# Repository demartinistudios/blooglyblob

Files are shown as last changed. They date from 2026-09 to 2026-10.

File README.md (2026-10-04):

<a href="https://demartinistudios.github.io/blooglyblob/">
  BlooglyBlob — open the build guide
</a>

# BlooglyBlob

**A 3D-printable AI companion that runs on Raspberry Pi and uses the OpenAI
API.**

Press the button to start a voice conversation. BlooglyBlob talks back, lights up,
moves his head and arms, and can dance to music. You build the character from
printed parts and purchased electronics, then install the Python application on
the Pi.

This repository contains the application, editable CAD, STL files, Bambu Studio
print projects, and illustrated assembly instructions.

**[Open the build guide →](https://demartinistudios.github.io/blooglyblob/)**

<a href="https://demartinistudios.github.io/blooglyblob/">
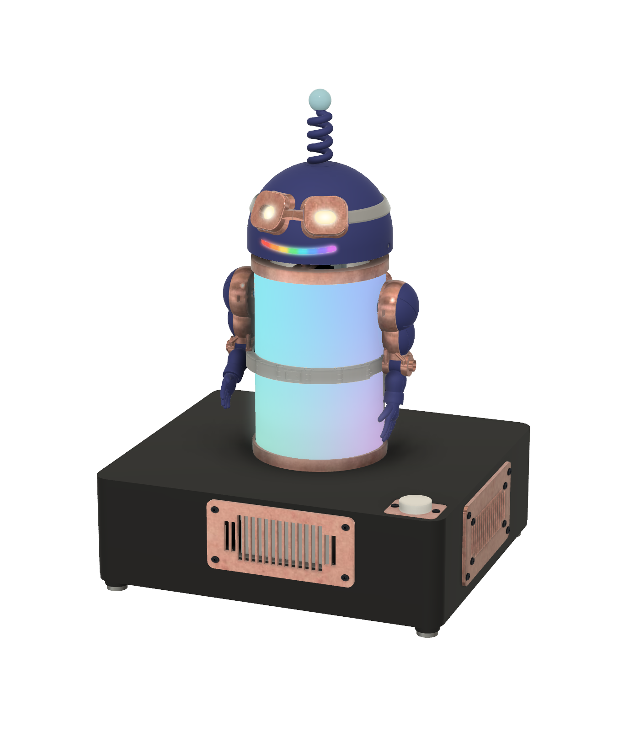
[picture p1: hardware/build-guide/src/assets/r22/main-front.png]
CAD view of BlooglyBlob lit up: glowing goggle eyes, a rainbow mouth and a softly lit body, with blue-violet head and hands, copper trim, and a black base with a conversation button
  
</a>

## Build your own

Start with the [build guide](https://demartinistudios.github.io/blooglyblob/).
It brings the parts list, print downloads, assembly drawings, wiring, Pi setup
and software commands together in one numbered sequence. You can read it and
download the print files without cloning this repository.

- **[Parts and supplies](https://demartinistudios.github.io/blooglyblob/#parts):** what to buy, quantities and tools.
- **[Print the parts](https://demartinistudios.github.io/blooglyblob/#step-print-plates):** Bambu Studio projects, raw STLs, plate layouts and print settings.
- **[Set up the Raspberry Pi](docs/software/setup.md):** Raspberry Pi Imager, Wi-Fi, credentials and installation commands. This is also covered in the guide.

The build uses a Raspberry Pi 3 Model A+, USB audio, speakers, NeoPixel LEDs and
servos. Expect 3D printing, soldering and some terminal commands. You'll need a
computer for setup, an internet connection and your own OpenAI API key with API
billing enabled. Conversations use cloud AI; API usage is billed separately from
a ChatGPT subscription. See the guide's parts list for the complete specifications.

**Project status:** this is a working development project, with physical assembly
and full-system validation still in progress. Review the
[current limitations](docs/release/publication-inventory.md#readiness-and-validation-scope)
before buying or printing parts.

## Using or changing the software

One Python application runs on the Pi and controls conversations, audio, lights
and movement. The installer sets it up as a service so it starts when the Pi boots;
the button starts a conversation.

- [Setup](docs/software/setup.md) — install and configure the application.
- [Maintenance](docs/software/maintenance.md) — update, inspect logs and troubleshoot.
- [Architecture](docs/software/architecture.md) — how the application and OpenAI connections work.
- [Contributing](CONTRIBUTING.md) — development setup, tests and contribution workflow.

Run `make help` from a checkout to see the available commands. Follow the setup
guide before running commands against a Pi.

## Find your way around the repository

| Location | What's there |
| --- | --- |
| [`blooglyblob/`](blooglyblob/) | Python application and device control |
| [`hardware/cad/`](hardware/cad/CURRENT-DESIGN.md) | Current editable CAD and exported geometry |
| [`hardware/printing/`](hardware/printing/current/README.md) | Bambu Studio projects and print guidance |
| [`hardware/build-guide/`](hardware/build-guide/README.md) | Guide source and local preview instructions |
| [`docs/software/`](docs/software/) | Setup, maintenance and software architecture |
| [`tests/`](tests/) | Automated software tests |

Open the full assembly as [Fusion (.f3d)](hardware/cad/current/assembly.f3d) or
[STEP AP214 (.step)](hardware/cad/current/assembly.step) in other CAD applications.
The STEP includes hidden reference and test geometry; see the
[CAD notes](hardware/cad/CURRENT-NOTES.md#portable-assembly).

For hardware or guide contributions, read the [hardware workflow](hardware/README.md).

## Safety and license

Build and use at your own risk. No safety or performance guarantees are made.
You are responsible for assembly, testing and use. BlooglyBlob is a hobby
project for adults, not a toy, and is not designed for children. The hands use
small, strong magnets that are dangerous if swallowed, and the microphone sends
speech to OpenAI under your API account. Read the
[safety and responsibility notice](hardware/SAFETY.md) before starting.
BlooglyBlob is not affiliated with or endorsed by OpenAI or any other company
named here. Raspberry Pi is a trademark of Raspberry Pi Ltd.

Original software, hardware designs and build materials are [MIT licensed](LICENSE).
See [license scope](LICENSING.md) for exclusions and separate audio terms.

The optional streaming feature uses TMDB and the TMDB APIs but is not endorsed,
certified, or otherwise approved by TMDB. Streaming availability data comes from
JustWatch through TMDB; optional deep links use data from
[Watchmode](https://www.watchmode.com/).

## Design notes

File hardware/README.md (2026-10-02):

# Hardware

For assembly, open the [build guide preview](build-guide/README.md#build-and-preview).
The guide’s **Build cost** page lists materials used, shopping totals and a
shopping list with purchase links; [BUILD-COST.md](catalog/BUILD-COST.md)
explains how they are calculated.
Website deployment and physical qualification are separate checks. For contributions, this page
connects the three area procedures:
[CAD](cad/DESIGN-WORKFLOW.md), [printing](printing/current/README.md), and
[guide authoring](build-guide/README.md). A contributor or fork can inspect the
current inputs, build the guide and propose changes without maintainer credentials
or Fusion MAIN access. An authorized maintainer performs upstream CAD promotion.

## Start from a fresh checkout

Use Python 3.12 or 3.13 and run these commands from the repository root. These
offline commands use only the Python standard library; the full
[development setup](../CONTRIBUTING.md) is needed for application work:

```sh
make hardware-check
make guide-build
```

If `python3` selects another version, add `HOST_PYTHON=python3.12` to each Make
command.

The first command checks offline invariants. Outstanding publication reviews are
separate: use `python3 hardware/tools/validation/check.py --publication` to inspect
them. The second
builds a local preview; success does not authorize publication. Neither requires
Fusion, Bambu Studio, scratch outputs, credentials or
physical devices. Browser verification and optional authoring dependencies are
in the [guide procedure](build-guide/README.md).

## Sources of truth

| Information | Maintained source |
| --- | --- |
| Accepted CAD identity and exact cloud version | [Registry](cad/design-control/registry.json); [current design](cad/CURRENT-DESIGN.md) is its generated summary |
| Required native and geometry exports | [Current CAD inputs](cad/current/), selected and hash-checked by the registry's input lock |
| Part identity and dependencies | [Part catalog](catalog/parts.json) |
| Editable print projects and process | [Current print set](printing/current/README.md) and [recipe locks](printing/recipes/projects.json) |
| Installed hardware and electrical allocations | [Hardware allocations](assembly/hardware.json) and [electrical tables](assembly/electrical.json) |
| Current technical limitations | [CAD notes](cad/CURRENT-NOTES.md), [print procedure](printing/current/README.md), and [guide review](build-guide/REVIEW.md) |
| Price quotes and consumption allowances | [Price catalog](catalog/prices.json); the guide calculates costs from these quotes, current quantities and plate weights |
| Purchased supply specifications | [Supply catalog](catalog/supplies.json); guide cards add presentation and links |
| Component references | [Reference catalog](references/community-20260925/catalog.json) linking to publisher documents |
| Assembly instructions | [Guide source](build-guide/src/), independent of CAD release selection |

Everything for the physical character belongs under `hardware/`, including
references, illustrations, tools and records. Software and repository-wide docs
belong under `docs/`; Pi device-control modules remain in `blooglyblob/hardware/`.

## One process, with separate stages

One person can perform all stages, or several owners can hand them off using the
same records and checks. Agree ownership before editing shared files.

1. Record the intent, accepted baseline, expected affected parts/interfaces and
   acceptance criteria in a unique ignored experiment run. Work in a separate
   CAD document; render or print trials only within the authorized scope.
2. Review the candidate's evidence and limitations. An authorized owner promotes
   only the accepted scope using the [CAD procedure](cad/DESIGN-WORKFLOW.md).
3. Identify affected geometry, placements, hardware, material/process, electrical
   and software dependencies. Record each downstream stage as `pending`,
   `blocked` or `verified` against its exact inputs. An unmapped impact needs
   review; a new global revision alone does not require rebuilding every output.
4. Update or verify affected [print recipes](printing/current/README.md) and
   [guide surfaces](build-guide/README.md). Record changed, reused and reviewed
   outputs with concise public evidence in the current review/provenance files;
   keep the detailed work record private.
5. Run offline checks, guide build and browser verification; review the assembly
   meaning and visuals before claiming a synchronized public build kit.

CAD may be accepted while printing or guide work remains pending. A qualified
build-kit release requires those dependencies and blockers to be resolved.
The development source and guide can be shared with their limitations stated;
see the [release checks](../docs/release/checklist.md).
Digital validation, machine completion, usable stock and physical fit/strength/
optical qualification are distinct evidence. A passing slice does not establish
physical qualification; printing and deployment are separate authorized actions.

## Retention

Keep one current required set of native CAD, geometry exports and editable print
inputs in Git, with compact provenance, exact hashes and current limitations.
A CAD checkpoint may precede print or guide acceptance. Guide prose changes need
no CAD release.

Keep experiments, candidate slices, renders and transaction backups in ignored
`hardware/.work/<category>/<run-id>/`. Existing detailed work records remain local
under ignored `hardware/records/`; printer queues, stock and job history belong in
ignored `hardware/printing/operations/`. Record owner, baseline, purpose, useful
results and next action there. Publish maintained inputs and necessary technical
conclusions, not work diaries or entire run trees.

Before cleanup, confirm ownership, identify all consumers and privately back up
unique useful work. Git does not protect ignored or uncommitted files. Keep active
work until its owner releases it; never make a public build depend on local notes.

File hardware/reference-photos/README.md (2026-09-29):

# Servo and horn reference photographs

Original project photographs document the Kitronik 25105 servo kit and its disk
horn. They show component identity, face features and hole arrangement. Perspective
prevents using the ruler or caliper display in an image as a precise dimension.

| Photograph | Shows | SHA-256 |
| --- | --- | --- |
| [Servo and supplied horns](kitronik-25105-servo-and-horns.jpg) | Kitronik 25105 label; disk, single-arm, double-arm and cross horns; screws | `7322c0b13f656a358c2336e57be936af8b65a79d01c99e360f1ec55198ba8b92` |
| [Disk spline face](kitronik-25105-disk-spline-face.jpg) | Raised center with splined socket on the servo-facing side | `059b7cd5e392d88aa05b36925ba0a877f83cc8d71fe194da4269afceabe6fa25` |
| [Disk outer face](kitronik-25105-disk-outer-face.jpg) | Smaller raised center around the screw opening | `a2165811ba410bba2b3c9a426b5e0594c0c1eafebf44c10f703b969b42033f11` |

The [servo reference](../servos/README.md#measured-disk-horn) records the separately
measured dimensions, including plate thickness, raised centers, mounting-hole
spacing and seated height. Consult its manufacturer links for the servo case and
spline specification. Measurements of this reference sample are not manufacturing
tolerances or proof of fit for every supplied horn.

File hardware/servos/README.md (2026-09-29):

# Servo reference: Kitronik 25105 / FS90MG-CL

The head and both arms use Kitronik Clippable Servo 25105, identified by Kitronik
as the Feetech FS90MG-CL. Each axis uses the supplied round disk horn and its
matching center screw. Follow the [build guide](https://demartinistudios.github.io/blooglyblob/)
for drilling, fastening and fitting the horns.

## Manufacturer references

- [Product page](https://kitronik.co.uk/products/25105-clippable-servo)
- [Technical drawing](https://resources.kitronik.co.uk/pdf/25105-kitronik-clippable-servo-technical-drawing.pdf): case, mounting ears, output and mounting-hole dimensions.
- [FS90MG-CL datasheet](https://resources.kitronik.co.uk/pdf/25105-kitronik-clippable-servo-fs90mg-datasheet.pdf): 21T spline and nominal 180° travel over 500–2500 µs.

Use the product-specific documents when selecting a replacement. Generic FS90MG
listings describe different analog/digital variants, spline counts and envelopes;
the name alone does not establish compatibility. The supplied horn center screw
is a separate interface from the M2 servo mounting screws.

## Nominal case dimensions

These dimensions are taken from the Kitronik drawing and used by the CAD
reference. They do not include print clearance or establish physical fit.

| Dimension | mm |
| --- | --- |
| Main body length × width | 22.5 × 12.1 |
| Main rectangular case height envelope | 22.4 |
| Height excluding spline / including spline | 26.7 / 30.7 |
| Mounting-ear overall span | 32.3 |
| Ear underside / top from case bottom | 15.7 / 18.2 |
| Mounting-hole spacing / diameter | 27.7 / 2.2 |
| Output axis to nearer mounting hole | 8.7 |
| Spline envelope diameter | 4.86 |

The CAD reference simplifies the molded case and output cap. Axis-to-case-end
placement uses symmetry inferred from the drawing.

## Measured disk horn

The [reference photographs](../reference-photos/README.md) show the supplied kit
and both disk faces. The following are measurements of the reference horn, not
manufacturer tolerances or measurements inferred from photograph scale.

| Feature | Diameter | Axial thickness / protrusion |
| --- | --- | --- |
| Flat disk plate | 23.55 mm | 1.61 mm |
| Servo-facing raised center | 6.75 mm outside | 2.17 mm above the plate face, derived as 3.78 − 1.61 |
| Outer raised center | 5.44 mm outside | 0.87 mm above the plate face, derived as 4.65 − 3.78 |
| Plate plus servo-facing raised center | — | 3.78 mm |
| Overall, including both raised centers | — | 4.65 mm |

The measured installed height is 3.33 mm from the uppermost flat plastic
output-cap face to the disk's broad underside, or 4.94 mm to its upper flat face.
The selected opposite mounting holes are approximately 18 mm apart and originally
about 1.1 mm in diameter; the guide specifies drilling that pair to 2.2 mm with
the horn removed. Other pairs are about 16 and 20 mm apart, so the holes do not
form a uniform four-hole pattern. Use the guide's current fastener allocations.

The horn envelope omits the spline socket, center bore and mounting holes.
The 6.75 mm measurement is the outside of the raised center, not the socket
diameter. Do not infer spline engagement or installed height from that envelope.
Keep access to the supplied center screw; the printed adapter fastens to the horn
rather than replacing its spline.

## Fitting and operating positions

The application uses a fixed **1000–2000 µs window at 50 Hz**. The fitting command
`make pi-servo-fit` holds the left arm at 2000 µs, right arm at 1000 µs and head at
1500 µs before the guide's horn installation steps. See
[servo setup and maintenance](../../docs/software/maintenance.md) and the
[servo fitting contract](../../docs/software/validation.md#servo-fitting-contract).

The datasheet gives no case-referenced angular zero or marked-tooth datum.
Horn indexing establishes the attached part's orientation. Nominal datasheet
travel does not establish loaded clearance, cable freedom or usable travel in the
assembled robot; physical qualification remains separate from the reference data.

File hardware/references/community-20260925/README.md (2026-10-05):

# Component reference catalog — 2026-09-25

[Catalog](catalog.json) maps required parts, consumables and fasteners to publisher product pages, pinouts, drawings and datasheets. Documents are external links. `download_url`, when present, selects the document endpoint for the guide; otherwise it uses `official_url`. Publisher PDFs are not version controlled or bundled. Optional research downloads belong in ignored `hardware/.work/` and are never required by a build.

The catalog is a reference supplement. It does not approve substitutions, qualify physical fit, change electrical limits or advance CAD/delivery acceptance.

## Coverage and limits

- Manufacturer-hosted PDFs cover the Kitronik servo, Adafruit eye boards and Pixel Shifter, Panasonic capacitor, Raspberry Pi board, MEAN WELL supply, Adafruit power-donor cable, YAGEO resistors and Zotefoams LD45. The two Kitronik links identify the manufacturer PDFs inspected on 2026-09-17.
- The Eaton S505H PDF is Eaton Technical Data 4406, effective June 2023, manufacturer-authored and hosted by LCSC. The build uses its 1 A time-delay selection for F2 in the single E07 holder. The catalog selects the verified distributor-hosted PDF because Eaton’s download endpoint is unreliable.
- The WAGO connector PDF is manufacturer-authored and hosted by NetXL; the catalog also links directly to WAGO's exact product page. This supplier mirror is explicitly identified.
- Exact product pages provide references for the Adafruit connector cables, mouth stick, speaker pair, button and quick-connect leads, plus Waveshare USB TO AUDIO and its supplied extension. The PNY Elite family page covers the selected 32 GB microSDHC card. The button has a publisher raster drawing link; it is not mislabeled as a PDF. The servo horn and center screw lack a separate manufacturer dimensional specification.
- Switchcraft 721AU and K&J D31 have verified official PDF links. Family documents are labeled and must be read for the specified variant.
- **E05 is Adafruit6026.** The exact product and manufacturer drawing establish the100-pixel,100mm-pitch strand. Adafruit family guides describe copper-marked positive conductors and factory lead colors. Lot variation remains possible; confirm identification and test input direction before cutting. Connector sex is not direction.
- **E24 and E25 use specification-matched purchasing examples.** E24 links to a 24 AWG DigiKey jumper lead and its datasheet. E25 requires four equal-height adhesive feet fitting the Ø14mm post faces. There is no defensible exact-model datasheet to attach.
- **C08 is a candidate, not a verified installed purchase.** K&J D31 matches the stated size. Retention and adhesive compatibility remain to be tested.
- **C02/C03/C04:** the user's selected [Coscom LD45 listing](https://coscomcosplaysupplies.com/products/plastazote-ld45) explicitly offers white 4 mm sheets. Its default selector is 2 mm, so purchasers must select 4 mm. The [Zotefoams LD45 sheet](https://www.zotefoams.com/wp-content/uploads/2025/03/PIS-A013-Plastazote-LD45.pdf) is Product Information Sheet A013, Issue 1 Revision 1, June 2026. It gives typical material properties, not guaranteed optical transmission. The superseded December 2017 URL returned 404; the current URL was obtained from Zotefoams' product information index.

## Verification and updates

The owner selected external links on 2026-09-26. The [link verification record](link-verification.json) records the September link scan and the three generic servo datasheets; later additions carry their own checked dates in the catalog. Direct PDF retrieval checks the PDF signature rather than treating an HTML error page as a document. Browser retrieval verified Panasonic and product pages that blocked or timed out under command-line access. These are dated availability observations; external sites can change.

Edit `catalog.json` as the authority, then update the guide's reference presentation and page. Preserve part identity, exact-model/family limitations and publisher or supplier-host attribution. Verify replacement links against the intended document before changing them. Do not recreate download-and-copy generators or add manufacturer PDFs to the source tree.

`make hardware-check` checks external URL shape, catalog/guide agreement, rendered-page links and the absence of publisher PDFs in the reference/servo directories. `make guide-browser` verifies the built guide. These contributor checks remain offline; deliberate live link verification is separate.

`tool-product-identity.json` records the separate tool check: Adafruit 136 is Ladyada’s Electronics Toolkit, whose contents link to Adafruit 2034, Digital Multimeter Model 9205B+. The current guide T03 photo uses 2034 but its purchase link pointed to 136 when checked; the guide owner was notified.

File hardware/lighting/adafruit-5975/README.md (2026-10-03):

# Selected eye board: Adafruit 5975

The build uses **two** Adafruit 5975 boards, one per eye, behind removable
Plastazote diffusers. The boards fasten to printed holders so they can be replaced
without glue.

- [Product and published envelope](https://www.adafruit.com/product/5975): 12.3 × 11.3 × 6.2 mm, M2 mounting, 3-pin JST-SH input/output.
- [Adafruit PCB source](https://github.com/adafruit/Adafruit-NeoPixel-Breakout-PCB), linked by the [manufacturer downloads page](https://learn.adafruit.com/adafruit-neopixel-breakout/downloads).
- Local unmodified source: [Eagle board](Adafruit-NeoPixel-JST-SH-Breakout.brd), [upstream README](upstream-README.md), [upstream license](upstream-license.txt). Designed by Limor Fried/Ladyada for Adafruit Industries; upstream identifies Creative Commons Attribution/Share-Alike. Preserve the supplied attribution and license with redistribution of these reference files.
- Local unmodified 3D model: [5975-NeoPixel-Breakout.step](5975-NeoPixel-Breakout.step), byte-identical to `5975 NeoPixel Breakout.step` in [Adafruit CAD Parts](https://github.com/adafruit/Adafruit_CAD_Parts). Copyright (c) 2016 Adafruit Industries, [MIT license](../../../LICENSES/Adafruit-CAD-Parts-MIT.txt).
- [Extracted mechanical interface](mechanical-interface.json), including source SHA-256, exact hole coordinates, outline dimensions and limits of the extraction.

The Eagle file uses millimeters. Two plain holes have diameter 2 mm and centers (0, +4.318) and (0, −4.318): **8.636 mm apart**. The LED is centered at (0, 0). Layer 20 outlines a 12.192 × 11.43 mm rounded board, with 2.54 mm corner radii. These are CAD nominal dimensions, not physical measurements or print clearances. The small difference from the product listing is retained explicitly rather than rounding the mounting pattern.

The overall 6.2 mm product envelope does not define the full front/back component
stack. Keep both connector plugs and wiring bends accessible; use the maintained
assembly instructions for screws, nuts and washers.

## Assembly use

The eye boards mount in P06 holders. Follow the
[build guide](https://demartinistudios.github.io/blooglyblob/) for diffuser placement,
fastening and wire routing. The selected [current design](../../cad/CURRENT-DESIGN.md),
[assembly allocations](../../assembly/hardware.json) and
[electrical tables](../../assembly/electrical.json) define the maintained build.
This reference does not replace those quantities, fastening choices or wiring.

Flexible wiring, physical plug access, diffuser fit and optical performance still
need physical review. The nominal foam thickness is 4 mm; it is not a measured
fit or guaranteed optical specification. Preserve access for both plugs and
avoid deriving the full component stack from the product envelope alone.

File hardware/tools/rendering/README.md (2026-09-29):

# Current rendering

Install `requirements.txt` into a local virtual environment. Dependencies were exercised with Python 3.12; the lock records exact installed versions. Do not commit the environment.

```sh
python hardware/tools/rendering/run.py --view r22/part-GS11 --font /path/to/licensed/font.ttf --output hardware/.work/rendering/new-run
```

Use `--view eye-details` for the five eye-interface illustrations. Other scene keys are in `hardware/rendering/scenes/views.json`. The runner resolves all inputs through `hardware/rendering/source-lock.json`,
checks the selected CAD identity and native/export bindings, and requires a new
output directory. Roles select current meshes, native mesh evidence, assembly,
joints, palette and scenes without relying on historical payload folders.
Scene dimensions must be explicitly reviewed for the selected CAD identity. It renders the current composed meshes directly. Cameras, palette, occurrence transforms and cm→mm conversion are retained. Each run records package versions and the supplied font's hash; the original illustration font was macOS Arial. Supply a legally available matching font for exact typography, or review the visual differences. No font is redistributed here.

A new native geometry export must update the current composed mesh and its provenance deliberately. Inspect bounds, volume, joints, appearance and visibility; keep unchanged rows exact. Review generated images before promoting them into guide source. Original CAD inspection screenshots remain immutable evidence and are not synthetically recreated by this renderer.

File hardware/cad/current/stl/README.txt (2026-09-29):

R23 geometry set: FB01 and FB41 replaced as a matched pair. FB41 is 2mm thick; four M3x6 screws/M3 nuts; round base mounts replace square posts. All other STL bytes unchanged from R22. 52 required shapes/75 installed pieces plus optional AR07; AR10/AR11 omitted. Bed transforms are explicit; FB41 front down. Geometry only: existing R22 C2/K1 project meshes and toolpaths are obsolete for FB41/FB01 and must be replaced and re-sliced. Printed fit, 1mm bearing web and 0.3mm nominal audio clearance are unqualified.

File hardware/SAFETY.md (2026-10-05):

# Safety and responsibility

## Your build, your responsibility

BlooglyBlob is a DIY electronics and robotics project. You are responsible for selecting components, printing, assembly, wiring, software configuration, inspection, testing, maintenance and use of your build, including any modifications. Evaluate whether you have the skills and equipment to do the work; get qualified help when needed. Following this guide or passing its checks does not establish that a build is safe, compliant or suitable for a particular person or purpose.

## Who it’s for and practical precautions

BlooglyBlob is a hobby electronics project for adults, not a toy, and is not designed for children. Keep it, and especially its small magnets, away from young children.

- Soldering, cutting and printing involve hot surfaces, fumes and sharp tools. Follow equipment and material instructions; use suitable ventilation and protective equipment.
- Use the specified Mean Well GST40A05-P1J (5 V, 5 A) power supply. The circuit is designed around its output and protection characteristics; do not substitute another supply.
- Fit the specified T1 A time-delay fuse in the lighting supply. Do not bypass it or fit a higher-rated fuse. Supply protection and the fuse do not guarantee that every fault clears before wiring or components overheat.
- Do not open the supply or work on mains wiring. Disconnect power before changing wiring; short circuits can cause burns or fire even at low voltage.
- Keep fingers, hair and clothing away from servos and joints. A jammed servo can keep pushing and overheat; stop immediately. Keep small parts away from young children and pets.
- The hands attach with small, strong magnets. If swallowed, magnets can cause serious internal injury. Check that each magnet is fully set in cured epoxy and inspect the hands regularly. Keep loose magnets and detachable hands away from young children and pets. If a magnet may have been swallowed, get medical help immediately.
- Keep the build dry, keep vents clear, and stop using it if wiring is damaged, parts overheat, or movement is obstructed. Do not leave powered tests unattended.
- AI responses can be incorrect or inappropriate. Do not rely on the robot for emergency, medical or other safety-critical decisions.

## Privacy, cloud AI and costs

The robot’s microphone sends speech to OpenAI under your API account. Tell people who talk to the robot that its voice is AI-generated and that their conversations go to a cloud service. You are responsible for following OpenAI’s terms and usage policies, including its rules on use by children, and the laws where you live.

API usage is billed to your OpenAI account. Use its billing controls to limit what you can spend. You are responsible for all charges.

## No warranty or safety certification

To the fullest extent allowed by applicable law, the project’s designs, print files, software, documentation and build instructions are supplied as is, without express or implied warranties, including merchantability, fitness for a particular purpose and noninfringement. The authors and contributors make no guarantee of accuracy, completeness, reliability, performance or safety, and do not represent that a build meets product-safety standards or regulatory requirements. Diagrams, test results, recommended components and completed checklists are not safety certification.

## Limits of liability

To the fullest extent allowed by applicable law, the authors, contributors and copyright holders disclaim liability for injury, property damage, data loss or other loss arising from building, modifying or using this project. Build and use it at your own risk. Nothing in this notice excludes a liability, warranty or legal right that applicable law does not allow to be excluded. The project license and third-party terms continue to apply; this notice does not replace them or add restrictions to the open-source license.

BlooglyBlob is not affiliated with or endorsed by OpenAI, Adafruit, Raspberry Pi Ltd, Autodesk or any other manufacturer or service named in this project. Product names and trademarks belong to their owners.

See the [MIT license](../LICENSE) and [license scope](../LICENSING.md).

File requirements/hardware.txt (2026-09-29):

# Additional Raspberry Pi audio and GPIO dependencies.
pyaudio>=0.2.14
gpiozero>=2.0
pigpio
rpi-ws281x>=5.0.0
RPi.GPIO>=0.7.1

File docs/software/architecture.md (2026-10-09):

# Application architecture

Blooglyblob runs as one Python application on the Raspberry Pi, started with
`python -m blooglyblob` and managed by `blooglyblob.service`. The button starts
a conversation. OpenAI supplies cloud AI; there is no local language model.
Follow [setup](setup.md) and [maintenance](maintenance.md)
for installation and operation.

## Internal responsibilities

| Module | Owns |
| --- | --- |
| `blooglyblob/application.py` | Startup, readiness, signals, shared API client, integrations, and shutdown |
| `blooglyblob/conversation.py` | Conversation, idle, dance, and alert transitions; activity generations and tool context |
| `blooglyblob/media.py` | Direct speech, scanner, drain, and media-release coordination |
| `blooglyblob/audio/` | Microphone capture, bounded PCM handoff, one speaker owner, mixing and resampling |
| `blooglyblob/hardware/` | Button, LEDs, servos, presentation, local dance/chime workers and diagnostics |
| `blooglyblob/ai/` | OpenAI Live, Responses, Speech, validation, persona and voice resources |
| `blooglyblob/tools/` | Tool schemas/execution, timers, Ring, Roku, and content lookup |

These modules call one another directly. There is no local brain/device server,
network protocol, device registration, or reconnect loop. OpenAI connections
still use the internet. The existing `pigpiod` daemon remains a GPIO prerequisite.
The application retains the root permissions required by the current LED/GPIO drivers.

## Settings and voice

Select one runtime file with `BLOOGLYBLOB_ENV_FILE`; the installed service uses
`/etc/blooglyblob/app.env`. Explicit process values take precedence. Files are
read literally without shell execution or variable interpolation. The root
`.env` contains host-side deployment settings and is not loaded by the application.

Bring your own `OPENAI_API_KEY`. Live, Responses, and Speech requests are billed
to your account. Defaults remain `gpt-live-1`, `gpt-5.6-terra`, and
`gpt-4o-mini-tts`, respectively; your account must support the configured models.
The [runtime template](../../config/app.env.example) lists model, audio and
integration settings. `OPENAI_INACTIVITY_SECONDS` defaults to 20 and
`OPENAI_SESSION_MAX_SECONDS` to 600. These bound one conversation, not total
spending. No provider fallback exists.

`blooglyblob/ai/persona.json` defines the character.
`blooglyblob/ai/voice_profile.json` supplies Ballad, delivery instructions, pace,
expression and pronunciation. `OPENAI_VOICE` overrides the shared voice;
`OPENAI_SPEECH_VOICE` can override finite announcements separately. The APIs use
different synthesis paths, so matching settings still need a listen on the Pi.

Optional ring modulation uses the profile's `output_effect` settings. It is
currently disabled (`mix: 0.0`), which preserves PCM unchanged. `mix` ranges
from 0.0 to 1.0; integer `carrier_hz` ranges from 1 to 400. It preserves sample
count, adds no lookahead or buffered tail, and never increases individual sample
magnitude. There is no automatic loudness processing or replacement DSP.
Restart the application after a profile change. Deploy accepted profile edits
with `make pi-update`; installed source edits are replaced by the next update.
Audio tuning and the existing clipping/follow-up investigation remain separate
from this architecture change.

## Audio formats

Internal speech is mono, signed 16-bit PCM at 24 kHz. The microphone captures
48 kHz and one continuous SoXR converter produces 24 kHz directly. Live receives
those samples unchanged, framed and paced for transport. Incoming Live/Speech
PCM stays at 24 kHz through optional coloration; the speaker writer converts it
once to the device's 48 kHz rate.

The same converter prepares the 16 kHz scanner recording once at startup and
converts the 16 kHz alert during file playback. Dance plays at its native
44.1 kHz stereo rate. Converted streams preserve filter state between packets;
normal completion flushes the short filter tail, while cancellation discards it.
There is no intermediate 16 kHz microphone format or codec transcoding. Current
device selection and microphone gain remain unchanged.

## Conversations and activities

Greeting preparation runs after local readiness and can make a billable Speech
request even before the first button press. A prepared greeting is reused;
otherwise Speech streams it on demand. Its existing voice and speed are retained.
Live connects concurrently. Microphone input is withheld until the greeting
physically drains, to avoid forwarding that locally generated speech as input.
Normal duplex capture resumes immediately afterward. A bounded queue covers any
remaining Live connection setup; stopping discards that session's input.

The scanner loops quietly through the conversation's speaker writer during web
search. Speech lowers its volume; microphone capture and incoming speech keep
flowing. Completion, failure or cancellation removes the effect. Background-only
samples do not drive talking gestures. Dance and
alert recordings use sequential speaker ownership.

When Live delegates a request, the application withholds speculative playback
while Responses decides which tool or answer is needed. This decision does not
close the microphone. Selecting a nonterminal tool reopens speech before the
work runs, so conversation can continue over the ducked scanner sound. Sleep and
dance keep playback withheld until the application's single finite announcement.
A result, failure, or new user speech releases the decision gate; the backend's
request deadline bounds the wait. New speech cancels an undecided request. Work
already running can continue, but older context cannot subsequently authorize a
sleep or dance transition. Tool arguments still pass schema validation; uncertain
actions are not automatically replayed under a new call ID.

Sleep/dance announcements must physically drain before the action starts.
Matching dance completion returns to conversation with the existing greeting.
Timers and doorbell alerts retain their preemption, acknowledgement, dismissal,
and time-limit behavior. An alert during an active alert is dropped; overdue
saved timers are discarded at startup rather than replayed.

Meaningful conversation activity resets inactivity; silent PCM does not. Owned
tool work suspends inactivity shutdown while the overall session ceiling still
applies. Optional integrations retain their existing roles and configuration.

## Completion and failure rules

- The conversation owns activity and generation decisions. Presentation never
  determines whether microphone input is accepted.
- Audio owns every speaker stream. Queue acceptance, effect removal, physical
  drain, and full driver release are distinct completions.
- The button mutes locally before waiting for the event loop or cloud. Stale
  audio and action results cannot reactivate a retired generation.
- Native workers must finish before their resources are released or reused.
  Cancellation of an await does not mean its thread stopped.
- Routine provider failure with confirmed closure returns to idle. Missing
  final usage alone is a warning when transport closure is confirmed.
- Unconfirmed ownership mutes and stops the application with exit status 73.
  The service does not automatically restart that status; inspect logs and
  restart explicitly after resolving the cause. Startup and shutdown have
  finite deadlines, including foreground execution and Python thread teardown.

Talking gestures and body lights follow actual speaker level while conversation
remains listening. Silence, drain, flush, mute and failures clear that level.
Pose holds and animation locks remain authoritative; sleep, dance and alert
presentation retain their existing behavior. Eyes are controlled separately.
The supported 16-pixel data chain uses body indices 0–5, eyes 6–7, and mouth
8–15. The mouth is explicitly dark during normal operation; this profile update
does not add a mouth animation. The [LED diagnostic](maintenance.md#supported-led-chain)
exercises every pixel without changing the F2-protected lighting supply.

## Verification

`make pi-status` and `make pi-logs` describe the single application service.
Readiness means required local initialization and controls completed; it does
not open a conversation or prove cloud access, acoustic quality, or movement.

`make dev-check` runs formatting, lint, type checks, and hardware-free tests without API
credentials. The [validation coverage](validation.md) separates offline checks
from physical qualification, including capture clipping and follow-up behavior
that still need evaluation in the complete assembly.

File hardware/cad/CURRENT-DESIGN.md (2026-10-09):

# Current Blue Glee Blob design

Open **Blue Glee Blob - MAIN** in Fusion → Admin Project.

Accepted design **R33**, exact cloud version **v30**.
Permanent file ID: `urn:adsk.wipprod:dm.lineage:nkM4P_10T7yYk-tasXlhbg`.

## CAD acceptance record

Recorded when this CAD revision was accepted; delivery status above may supersede downstream status below.

Accept the chamfered front upright P43, reinforced flush head-servo carrier P04, distinct lower P11/upper P42/rear-mounted middle P12 light brackets, and six LED placements. Retire P13 wire guide; rear P02 and unrelated geometry remain unchanged. Full native and STEP reimports verified; guide update remains pending.

## Current inputs

[Fusion assembly (.f3d)](current/assembly.f3d) · [STEP assembly (.step)](current/assembly.step) for other CAD applications.

[Native assembly and selected exports](current/) · [Parts catalog](../catalog/parts.json) · [Print projects](../printing/current/) · [Build guide](../build-guide/README.md)

The registry selects CAD authority. Its mandatory input lock is checked even without a delivery. A delivery binds the print recipes, parts catalog and renders to that CAD; it does not approve physical fit. The build guide is not part of the release: it reads these files when it is built.

## Checks

`python3 hardware/cad/design_control.py check` validates the mandatory current set, accepted native and any selected delivery.

The [workflow](DESIGN-WORKFLOW.md) defines experiments, promotion and recovery.

No local check queries live Fusion or establishes print completion, fit, strength or optical acceptance.

Generated from [registry.json](design-control/registry.json); use the render command after a reviewed registry update.

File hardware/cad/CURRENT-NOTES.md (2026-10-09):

# Current hardware notes

The registry selects R33, Fusion cloud version 30. The native assembly, STL
exports and print projects are the maintained build inputs. Historical revision
names in current evidence identify the source of unchanged features.

## Portable assembly

Download the [Fusion assembly (.f3d)](current/assembly.f3d) or the
[STEP AP214 assembly (.step)](current/assembly.step). The STEP exports the full
R33/cloud30 assembly, including hidden reference, layout and test components.
Reimport into Fusion retained all 562 bodies and 330 occurrences in their assembly
positions. It contains geometry and component placements, without Fusion
parametric history or joints. Body names and occurrence suffixes may change on import.
[Export provenance](current/step-export-provenance.json) records the source,
hash and measured reimport checks.

## Body lighting and head carrier

R33 uses five changed pieces: P43 front upright, P04 head-servo carrier,
P11 lower light bracket, P42 upper light bracket and P12 rear-mounted middle
light bracket. P02 is now the unchanged rear upright only. The P13 wire guide
is retired. There are 70 required printed pieces across 52 types, plus one
optional print instance. P10 seam covers, base and shoulder carrier are unchanged.

P43 has a deeper front chamfer, local fastening lands and an inset P04 mounting
seat. Its opposite M3 nut recess is fully recessed relative to the post's flat
side; the chamfer exposes part of the perimeter. Use an M3×10 countersunk screw
for this sideways front carrier connection. Nominal projection is 0.34 mm beyond
the nut, so verify full nut engagement without crushing the printed seat. This
is the designed length, not a confirmed record of the owner's trial screw.
The rear carrier connection retains M3×20.

P04 thickens the front servo-ear crossbar to 5.3 mm with a shallow 1.8 mm nut
recess and 3.5 mm of solid bearing above it. Both servo screw heads face upward:
front M2×8 and rear M2×6, with ordinary M2 nuts below. The servo shaft points up
at the rear end of its body, away from the front post. Assemble the servo and
carrier on the bench while the underside nuts are accessible.

P11 and P42 mount behind the front upright using two M3×14 countersunk screws
and two M3 nuts. Install the upper light bracket before the servo carriers block
access. P12 retains the rear mounting and brings its LEDs forward to the middle
height. Retain six Pebbles and two ties per Pebble. The lower and middle pad ends
have a 6 mm gap: bend the lower top exits behind their pads and the middle bottom
exits toward the LED-facing side, after clearing the end ties. Keep excess slack
out of servo movement and screw access. The local modeled wire envelope is
5×0.95 mm with a 5 mm bend radius; the complete strand slack was not simulated.

[Native and interface evidence](current/evidence/body-lighting-r33.json) records
geometry and clearance checks. The accepted trial improved assembly and lighting;
it is not a quantified strength or optical qualification. The inherited carrier
tab edge has only 0.2 mm modeled upper-bracket clearance, while added reinforcement
clears its adjacent bracket root by 1 mm. Check printed parts before tightening.

Guide illustrations, assembly order, hardware lists and supply cards are pending
an independent guide update. CAD acceptance does not mark that work complete.

## Body foam reference

C04 is a display-only 4 mm shell, with radii 34.1–38.1 mm and height 114.3 mm.
Two round Ø14 mm holes lie on the shoulder X axis at Z = 90 mm. The rear (+Y)
seam has a continuous 2 mm gap, without windows, knife slits or edge notches.
Backing ribs remain unchanged; the foam edges compress against them.
[Native verification](current/evidence/body-foam-r32.json) and
[print reuse](../printing/current/checks/r32-print-reuse.json) record this reference-only update.
Guide images showing the foam require regeneration from the current render inputs.

## Electrical references

The assembly contains one lighting fuse holder, F2, in its accepted location.
The F2 placement and all eight arm joints remain unchanged by R33. See [native verification](current/evidence/fuse-reference-r31.json)
and [print reuse evidence](../printing/current/checks/r31-print-reuse.json).

## Enclosure and board layout

FB01 uses open nut recesses and flat adhesive mounting faces for four WAGO
connectors. The Raspberry Pi and paired level shifters use the R28 mounting
positions. The WAGO row is ordered W1, W3, W2, W4 from rear to front. Use the
current assembly drawing and electrical tables for connector orientation and
terminal assignments. Do not infer wiring from the connector order alone.

The front microphone grille uses four M3 × 6 screws and ordinary M3 nuts; the
rear grille uses M3 × 12. Front nuts are loaded before the audio cradle.
Rear vent, power jack and audio mounting recesses have open loading access.
Glue only the eight board nuts, four bottom-cover nuts and three audio-cradle
nuts. Hold the grille, rear-vent and power-jack nuts until their screws catch;
do not glue them. Fastener counts and allocations are maintained in
[hardware.json](../assembly/hardware.json).

## Head shelf

P08/P14 use the same three M3 × 8 screws and M3 nuts with the fastening
pattern rotated 60 degrees. Assemble this joint on the bench before installing
the head/mouth. The head shell and P31 remain unchanged.

P08/P14 use direct native STL exports with closed edges at exact serialized
coordinates. Their source frames and the Fusion design are unchanged;
[export provenance](current/stl/head-export-provenance.json) records the checks.

## Audio cradle

FB24 has a solid rear tape surface. Attach the USB module's rear face, opposite
the microphones, to that surface with tape under 1 mm thick. Do not cut open the
closed rear slits. Keep microphones exposed and follow the guide's module-first
installation sequence. Actual tape adhesion and USB connector clearance remain
physical qualification items. R29 enlarges the USB opening to 15.5 × 17.6 mm
and moves the left lid fastening 12.85 mm rearward onto a matching lid tab.
FB24 and FB32 change; the two M2 × 8 lid screws and base mounting stay the same.

## Backpack

P35 includes 1.5 mm hinge-root blends and tapered ribs extending outward up to
2 mm. Hinge gaps, pin seats and screw access are retained. Remove supports without
forcing the ears apart. Printed strength and support removal require physical
qualification.

P36 canisters now have smooth 2 mm walls without internal fastening nuts.
The two corresponding P35 screw passages are closed. Bond the canisters at
the ring contact surfaces and bond the existing elbow/nozzle joints with
suitable epoxy. The two canister M3 × 8 screws and two M3 nuts are eliminated;
the backpack-to-carrier screws and belt joints remain removable.

## R29 downstream work

CAD is accepted. Guide images, instructions and supply allocations now reflect
all six affected part families, including removal of two canister screws and
two nuts. Scoped digital guide review and focused checks passed. Print preparation
replaces all seven P08/P14/FB24/FB32/P35/P36 instances and includes full W1/W2/C2
slicing and digital support review. Five localized W1 support blockers clear the
P08 nut pockets and relocated audio nut slot and screw bore. Accessible cradle
supports and backpack hinge-gap supports still require removal. Final package
integration and combined checks are recorded in the current printing receipts;
no physical print was dispatched as part of this preparation.

## Current print and rendering evidence

The [print procedure](../printing/current/README.md) describes selected projects,
settings and support removal. Its `checks/` directory retains compact digital
review evidence for the current geometry and inherited recipes. Whole-plate
estimates are predictions. Prior K1 support inspection covers the moved board
posts, nut recesses and WAGO mounting bands; W1 and W2 retain their documented
cradle and backpack reviews.

The [render source lock](../rendering/source-lock.json) selects the R33 assembly
mesh, native exports, palette and service-stand mesh. The stand originated in
R23; the renderer checks its transforms, body volumes and bounds against the
current assembly before reuse. A historical name does not imply a second design.

## Qualification limits

Digital input checks, slicing and guide review do not establish printed fit,
adhesive retention, cable reach, mechanical strength, acoustic performance or
complete powered operation. The current print-source comparison receipt covers the selected R33 instances.
Guide synchronization remains pending. See the [semantic review contract](../printing/recipes/README.md)
and [guide review summary](../build-guide/REVIEW.md). No synchronized kit delivery
is selected in the registry.

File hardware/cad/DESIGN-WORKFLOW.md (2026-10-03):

# CAD experiments, promotion and recovery

Start with the [hardware workflow](../README.md), then read
[CURRENT-DESIGN.md](CURRENT-DESIGN.md) and its source,
[registry.json](design-control/registry.json). The registry selects the only
accepted MAIN by permanent Fusion file ID, exact design release and cloud
version. Names, timestamps, larger revision numbers and the active tab do not
establish authority. Design revisions and Fusion cloud save versions are separate
sequences. Never create another MAIN with Save As.

The accepted assembly is available as [Fusion (.f3d)](current/assembly.f3d) and
[STEP AP214 (.step)](current/assembly.step). The STEP includes all hidden reference
and test geometry; see [portable assembly notes](CURRENT-NOTES.md#portable-assembly).
For a STEP-only refresh, export the exact accepted root component, including hidden
bodies and components, and reimport into a new document. Verify body counts,
placements and geometry before updating the export provenance and current-input
selection through the same lock and publication transaction. Do not save MAIN or
regenerate unrelated exports for this representation-only operation.

## Propose and test a change

1. Run `python3 hardware/cad/design_control.py check` from the repository root.
   Read the selected release, current input lock and [current notes](CURRENT-NOTES.md).
2. When using live Fusion, inspect file ID, saved/latest cloud version,
   processing completion and unsaved changes. The offline checker cannot do
   this. Preserve and reconcile any discrepancy before mutation.
3. Work in a separate experiment document and unique ignored
   `hardware/.work/experiments/<topic>/<run-id>/`. Record owner, intent, parent
   release/hash, cloud identity if available, expected changed parts/interfaces,
   acceptance criteria, checks, limitations and disposition. Contributors without
   MAIN access can submit their candidate and evidence for maintainer review.
4. Use `python3 hardware/tools/cad/impact.py PART_ID` as a starting point for
   affected plates, scenes, steps and interfaces. Review mating parts without
   automatically changing them. Keep eye-local, assembly and bed frames explicit.
5. Record actual trial results separately from predictions. Preserve the exact
   native/project/settings identity of printed trials. Use the maintained export
   helpers below; verify their explicit input identity before use.

## Promote the accepted scope

Only the authorized promotion owner updates MAIN. The local lock is cooperative;
it does not prevent another Autodesk user from editing. Other owners may continue
isolated experiments and downstream work without holding this lock.

1. Record scoped acceptance, baseline and expected outputs. Acquire the lock:
   `python3 hardware/cad/design_control.py lock --owner OWNER`.
   Never remove another owner's lock or expire it automatically.
2. Recheck live MAIN identity, latest/saved state and the lock's registry digest.
   Preserve every affected unsaved document. A changed baseline requires
   reconciliation; it must not be forced through the old acceptance.
3. Integrate and review a candidate in a separate document. Verify intended
   geometry and unrelated bodies, joints, appearances, placements and visibility,
   including hidden geometry. Avoid broad recomputation or silent mesh repair.
   Check printable solids and affected interfaces.
4. Export and integrity-check a fresh native MAIN backup before mutation.
   Recheck the baseline, apply only the reviewed scope to the existing lineage,
   and save with the acceptance/change description. Wait for cloud processing;
   verify the permanent file ID, new cloud version and saved state.
5. Export native and matching required geometry into a new ignored candidate
   directory. Verify native reimport, mesh geometry and source/frame provenance.
   Label partial downstream packages honestly; CAD acceptance may precede print
   preparation or guide updates.
6. Update compact public provenance with parent identity, before/after cloud
   versions, changed IDs/hashes, approval scope, validation and limitations.
   Keep detailed acceptance history and transaction backup locations in ignored
   local notes; do not link public inputs to them. Stage the complete
   selected current input set and any delivery record; validate their bindings before selecting
   them. Advance the registry last and regenerate CURRENT-DESIGN.md. Current
   checks remain mandatory when no delivery is selected.
7. Run `python3 hardware/cad/design_control.py check`. Record completion or a
   safe abort, then release your own lock:
   `python3 hardware/cad/design_control.py unlock --owner OWNER`.
   Commit the accepted files and necessary public provenance together after the relevant
   checks pass. Keep transaction backups until the saved selection is verified.

Keep a transaction checkpoint across interruptions; the registry alone cannot
explain a half-finished cloud save or file installation. If the cloud is newer
than the selected accepted revision, preserve it as an unreviewed candidate and
reconcile it. Do not infer acceptance from its existence. Inspect the owner and
actual state of a leftover lock before completing or abandoning a transaction.

## Portable helpers

`hardware/tools/cad/export.py` takes an explicit request with `cloud_file_id`,
`cloud_version`, `part_ids`, `include_hidden` and a new `output` directory.
`python3 hardware/tools/cad/export.py --validate-request REQUEST.json` checks the
request offline. Its `export(request)` adapter runs inside Fusion against an
already open, clean document; it does not save or mutate the design. This adapter
has offline validation tests but has not yet been qualified in live Fusion.
Native reimport, bed-frame export and design acceptance remain separate checks.

For local publication, mirror the intended repository paths in a new candidate
directory, including the new registry and its generated current-design summary.
Use `hardware/tools/cad/publish.py stage --candidate DIR --journal NEW_DIR
--owner OWNER --file PATH` with one `--file` per changed path; registry and summary
are required. Staging checks the resulting complete selection without changing
the checkout. With your promotion lock held, run `publish.py install --journal
DIR --owner OWNER`. It checks the baseline, preserves before/after bytes and
installs the registry last. An interruption leaves a marker that blocks current
checks; `publish.py recover --journal DIR --owner OWNER` restores the recorded
prior files only after ruling out conflicting edits. Keep the journal until the
accepted selection is committed and verified. None of these commands changes live
CAD or machinery.

## Recovery

Preserve questionable or interrupted state before repair. Restore the exact
native/export/project bytes from the recorded Git commit or tag, checking their
manifest hashes in a separate ignored recovery workspace. Verify the restored
selection before using it.

If MAIN needs restoration, restore the accepted geometry into the same permanent
cloud lineage as a **new cloud version**. Verify it and create a new recovery
acceptance record with that version. Preserve the previous accepted revision in
Git. File installation recovery must preserve the transaction's before/after evidence and
reconcile the registry with the verified complete set before work resumes.

## Handoff to printing and the guide

Record affected inputs and downstream disposition in the local work record;
maintain the reproducible public bindings and current limitations separately.
A native occurrence-transform change can affect assembly fit, service clearance,
kinematics, fastening and images even when STL bytes stay identical. Correcting
an export that omitted an already accepted placement is a representation repair;
verify that distinction against the native source.

Follow the [print procedure](../printing/current/README.md) for affected full
plates and the [guide procedure](../build-guide/README.md) for affected content.
The guide has a manual release checklist and is not pinned by the CAD registry or
delivery. Release the CAD lock after safe completion; do not hold it while waiting
for guide prose or a physical print.

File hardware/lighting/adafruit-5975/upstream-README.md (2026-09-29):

## Adafruit NeoPixel Breakout with JST SH Connectors PCB

<a href="http://www.adafruit.com/products/5975"><br/>
Click here to purchase one from the Adafruit shop</a>

PCB files for the Adafruit NeoPixel Breakout with JST SH Connectors.

Format is EagleCAD schematic and board layout
* https://www.adafruit.com/product/5975

### Description

This little breakout makes it easy to add a single NeoPixel to a project, with mounting holes and a pluggable connector. The PCB is less than 0.5"x0.5" and comes with two 3-pin JST SH 1mm pitch connectors for input and output. On the opposite side, a 5050 (5mm square) classic RGB NeoPixel that can be powered and controlled with 3.3V or 5V power.

The two mounting holes are M2 size and have clearance for the screw head, or could be used for sewing onto a fabric backing or attaching to a small model. Of course this design will never be as affordable as a pre-made strand with dozens of LEDs, but there's probably some time it would be useful - especially since it can be easily swapped out.

Comes as a single NeoPixel, no cables included so check out our JST SH compatible cables in plug or socket.

### License

Adafruit invests time and resources providing this open source design, please support Adafruit and open-source hardware by purchasing products from [Adafruit](https://www.adafruit.com)!

Designed by Limor Fried/Ladyada for Adafruit Industries.

Creative Commons Attribution/Share-Alike, all text above must be included in any redistribution.
See license.txt for additional details.

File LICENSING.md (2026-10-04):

# License scope

The [MIT license](LICENSE) applies to this project's original materials:

- Code and configuration in `blooglyblob/`, `scripts/`, `tests/`, `config/`,
  `tool_configs/`, `systemd/`, and `.github/`.
- `Makefile`, `pyproject.toml`, dependency requirement files, and configuration
  examples used to build, develop, or deploy that software.
- Associated software documentation: `README.md`, `CONTRIBUTING.md`,
  `SECURITY.md`, `AGENTS.md`, `CLAUDE.md`, `docs/software/`, and
  `docs/openai-mode.md`.
- Original CAD designs and exports, print projects, hardware and build-guide
  documentation, tools, photographs, illustrations, and other original project
  materials. DeMartini Studios LLC extended MIT coverage to these materials on
  2026-09-26.

The MIT grant above does **not** cover third-party materials, including
publisher datasheets, component drawings, imported vendor CAD, the Raspberry Pi
Imager screenshots in `hardware/build-guide/src/assets/setup/`, the build
guide's typefaces (SIL Open Font License 1.1) and GitHub mark in
`hardware/build-guide/src/assets/`, the Contributor Covenant text in
`CODE_OF_CONDUCT.md`, or dependencies. Their owners' licenses, terms and
rights govern them, even when stored alongside original files. The
ElevenLabs-generated dance song and its beat and light data in `songs/` are not
offered under MIT; see the soundtrack notice below. The two recordings in
`sounds/` are dedicated to the public domain under CC0; see below. The
DeMartini Studios logo is also excluded; see [Names and logos](#names-and-logos).

## Adafruit board models and files

The CAD includes unmodified 3D models of two Adafruit boards from
[Adafruit CAD Parts](https://github.com/adafruit/Adafruit_CAD_Parts):
the 5975 NeoPixel Breakout and the 6066 Pixel Shifter. In
`hardware/cad/current/assembly.f3d` and `hardware/cad/current/assembly.step`,
the 5975 model is the `REF Adafruit 5975 source STEP - hidden` component, and
the 6066 model is copied into the `REF 6066 SOURCE - Adafruit STEP - hidden`,
`REF BASE PixelShifter6066 - manufacturer STEP`, `FBREF Shifter S1` and
`FBREF Shifter S2` components. The 5975 model is also stored as
`hardware/lighting/adafruit-5975/5975-NeoPixel-Breakout.step`, and both models
appear as mesh bodies in `hardware/rendering/r28-visible-meshes.json.gz`. The
build guide's CAD step renders show the boards using these models.

These models are Copyright (c) 2016 Adafruit Industries and are distributed under
the [MIT license](LICENSES/Adafruit-CAD-Parts-MIT.txt). Keep that notice with any
copy of these files. Adafruit's Eagle board file and upstream README in
`hardware/lighting/adafruit-5975/` are a separate source under the
[Creative Commons Attribution-ShareAlike 3.0 Unported license](hardware/lighting/adafruit-5975/upstream-license.txt).

## Project soundtrack: separate terms

`songs/dance_song.wav`, `songs/dance_song_beats.json` and
`songs/dance_song_lights.json` accompany this robot project and its software.
The soundtrack was generated using ElevenLabs under a paid Creator
subscription.

DeMartini Studios LLC includes these files in the public project based on
ElevenLabs AI support guidance confirming repository/software inclusion and
continued use after the subscription ends. They remain subject to the applicable
[ElevenLabs terms](https://elevenlabs.io/terms-of-use), rather than this project's
MIT license. Do not redistribute or resell the music as a standalone audio asset
or music library. No unrestricted music license is granted by this repository.

The support response is guidance, not a separate license or amendment to those
terms. See the [publication record](docs/release/publication-inventory.md#dance-song)
for the inclusion decision. This notice must accompany distributions of
the soundtrack with the project.

## Synthesized sound effects: CC0 1.0

DeMartini Studios LLC dedicates the following original synthesized recordings
to the public domain under [CC0 1.0 Universal](LICENSES/CC0-1.0.txt), to the
extent of any copyright and related rights held in them. Applied 2026-09-21.

The two-note alert, `sounds/alert_16k.wav`, generated by
`scripts/generate_alert_sound.py`:

`SHA-256: 94277132c2c69b0a213026a74c3a7cce01150f05749b42d82ad71631eb0b0ad5`

The 30-second scanner, `sounds/search_16k.wav`, generated by
`scripts/generate_search_sound.py`:

`SHA-256: 996167f74612584a9f425be41980e5abb9bcbddffe6e76cd10c4da6ff46ed1b8`

These may be reused without attribution, including commercially, under CC0's terms.
Their generation scripts remain MIT software. This dedication does not apply to
the older unknown-source recording previously stored at the same path, the dance
song, its beat and light data, or any other media.

## Names and logos

The DeMartini Studios logo
(`hardware/build-guide/src/assets/demartini-studios.svg`, also drawn inline in
the build guide's footer) is not offered under MIT or CC0.
DeMartini Studios LLC reserves all rights in it. The BlooglyBlob robot mark and
the guide's other original illustrations remain under MIT.

No license in this repository grants a right to use the DeMartini Studios or
BlooglyBlob names or logos to suggest that DeMartini Studios LLC endorses a
work, is affiliated with it, or that a modified version is the official
project. You may state accurately that a work is based on BlooglyBlob.

The [release asset inventory](docs/release/asset-manifest.json) records the
provenance and redistribution scope of project media. Third-party CAD and board
files keep their source and license notes beside them, as in
`hardware/lighting/adafruit-5975/`. This scope document travels with the
software license in Python packages and Pi installation payloads.

Maintainer contact: anthony@demartinistudios.com.

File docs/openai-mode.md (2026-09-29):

# Application architecture

The current [application architecture and behavior](software/architecture.md)
guide describes the single Raspberry Pi application.

See [completion and failure rules](software/architecture.md#audio-lifecycle-invariants)
for audio ownership, interruption, and confirmed release.

This pointer preserves links from historical plans and hardware/build-guide evidence.

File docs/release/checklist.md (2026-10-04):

# Publication and validated-release checks

Use the [publication inventory](publication-inventory.md) for current findings and
[license scope](../../LICENSING.md) for grants and exceptions. A public development
repository and a validated build kit are different milestones. The owner approves
the visibility change; source availability does not certify hardware readiness.

## Public development repository

- Stage only the reviewed, explicitly named public files and run
  `make publication-check`; this checks the staged Git index, not unstaged edits.
  It is also included in `make check`.
- Review the exact source selection and intended Git history for credentials,
  private information and redistribution rights. Include native metadata, images,
  packaged downloads and any superseded GitHub commits still retrievable by SHA.
  Review GitHub Actions logs/artifacts and other hosted content too. A history
  rewrite alone does not remove server-side cached objects.
- Exclude local credentials, calibration, machine state, experiments, caches and
  environments. Keep publisher documents as external links, with no previous
  copies accessible from the public repository. Rotate confirmed exposed secrets.
- Include `LICENSE`, `LICENSING.md` and `LICENSES/`: DeMartini Studios LLC's
  MIT grant, exclusions, Adafruit MIT notice, CC0 sound-effect notice and
  [separate soundtrack notice](../../LICENSING.md#project-soundtrack-separate-terms).
  Confirm the guide footer credits and each print ZIP's `LICENSE.txt`.
- Confirm the GitHub destination, selected refs and public commit identities.
  Use the agreed clean history and maintainer business email. Do not change
  visibility, rewrite history or publish to another destination without approval.
- State prominently that this is a development prototype with an unverified build
  guide. Link current limitations; do not mark pending hardware reviews as passed.
- Verify contributor checks for the intended source, plus focused checks after
  documentation changes. Keep the local guide preview available independently of
  release qualification, using the [guide procedure](../../hardware/build-guide/README.md#build-and-preview).
- Resolve the recorded publication blockers, then obtain the owner's approval to
  change visibility. Recheck the remote state immediately before that action.

## Hosted development guide

Website deployment and hardware qualification are separate decisions. The Pages
workflow requires current-input integrity, a successful guide build and browser
checks. Pending kit reviews remain visible in its job summary; they are not
converted into approvals and do not alone prevent website deployment.

- Apply the source/privacy/rights checks above to everything the site distributes.
- Run `python3 scripts/check_pages.py` and `make guide-browser`. The first command
  uses the existing offline validator and reports outstanding reviews and kit
  delivery selection. Input errors or an invalid validator result fail the job.
  The second builds the guide and checks routes, links, images and interactions.
- Inspect the outstanding reviews before making readiness claims. Passing website
  checks does not prove geometry equivalence, connector fit or physical assembly.
- Obtain the owner's authorization to publish. Verify the successful deployment
  and public URL before reporting that the site is live.

The [guide procedure](../../hardware/build-guide/README.md#publication-readiness)
and [workflow](../../.github/workflows/guide-pages.yml) define website checks.

## Validated build kit

The following remain required before claiming a synchronized, qualified kit.
They do not need to be complete merely to share development source or host the
development guide.

- From a fresh source checkout, run `make dev-setup`, `make guide-setup` and
  `make check` as documented in [contributing](../../CONTRIBUTING.md). Verify
  installed-package resources and downloadable CAD/print inputs too.
- Run `python3 hardware/tools/validation/check.py --publication` and resolve all
  pending source comparisons, stale review evidence and unsupported commands.
  Review affected assembly views, instructions, supply/fastener allocations and
  downloads against the same accepted inputs. Automated checks do not prove fit.
- Complete a fresh Imager-to-Make installation on the reference Pi with a custom
  hostname/user, repeat provisioning, reboot and exercise update failure/repair.
  Record board, image, Python, dependency versions and release commit.
- Complete the [physical and acoustic qualification](../software/validation.md#physical-qualification)
  with current hardware, then repeat relevant checks on replacement audio before
  making replacement-kit claims. Device tests require explicit authorization.
- Have a fresh builder follow the software and hardware guide together. Record
  unresolved fit, strength, wiring and optical results honestly.
- Review the exact generated build-kit contents and metadata. Before distributing
  a prebuilt environment or image, assess its dependency licenses and notices.
- Obtain the owner's approval for the qualified release. A successful
  preview, slice or print does not establish physical qualification.

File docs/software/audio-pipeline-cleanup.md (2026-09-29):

# Audio pipeline

The application uses mono PCM16 at 24 kHz for speech and the configured OpenAI
Live connection. Physical 48 kHz microphone capture converts directly to 24 kHz;
the cloud transport does not resample it. See the
[runtime architecture](architecture.md) for ownership and session behavior.

## Conversion and playback

One streaming PCM converter serves capture, speech playback, scanner preparation
and converted WAV playback. It preserves filter state across packets, exact
finite-stream duration and end-of-stream flushes. Stopping capture discards
buffered input from the retired generation.

The 16 kHz alert/scanner assets convert at the 48 kHz speaker boundary. Dance uses
its native 44.1 kHz stereo rate. Optional voice coloration preserves bit-exact
playback when disabled, generation isolation and the finished-generation guard.
Actual driver drain/release futures and talking-level callbacks remain distinct
from packet delivery; cancellation must not release audio ownership prematurely.

## Verification and limits

Offline tests cover capture and transport contracts, anti-alias filtering,
finite-stream sample counts/tails, split-packet equivalence, gain preservation,
file completion/cancellation, voice coloration, scanner ducking and lifecycle
failures. See [software validation](validation.md) for test destinations and
remaining physical qualification.

Device acceptance requires listening through conversation, search and follow-up
questions, interruption, dance and alerts. Check pitch/duration and scanner
ducking, and inspect capture/output overflow, playback failure, unexpected idle
transitions and exit 73. Investigate ownership and input delivery rather than
changing gain or increasing queues to hide faults. Offline checks cannot
establish USB/ALSA timing, acoustic echo or clipping performance on the Pi.

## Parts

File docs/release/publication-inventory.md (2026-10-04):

# Publication inventory

The public repository contains the application, current hardware inputs, build
guide and tools needed to reproduce them. Development source, a hosted guide and
a qualified build kit are separate milestones; use the [release checklist](checklist.md).

## Public selection

| Area | Maintained contents |
| --- | --- |
| Software | Application, scripts, configuration examples, requirements, tests and service definitions; [contributor setup](../../CONTRIBUTING.md) |
| Hardware | Native CAD and exports selected by the [registry](../../hardware/cad/design-control/registry.json), current editable print projects, catalogs, assembly requirements and necessary provenance |
| Guide | One authored `hardware/build-guide/src/` tree; `make guide-build` derives ignored pages and downloads from maintained inputs |
| References | [Component-reference catalog](../../hardware/references/community-20260925/catalog.json) with external publisher links and original measured photographs |
| Media | Assets, source identity, hashes and rights in [asset-manifest.json](asset-manifest.json) |

Personal printer operations, detailed work records, plans and investigations stay
local in ignored folders. Keep credentials, calibration, machine configuration,
experiments, generated guide output and dependency environments out of the public
selection. Public builds must work without those files. Follow the
[hardware retention policy](../../hardware/README.md#retention).

## Readiness and validation scope

[Software validation](../software/validation.md) separates offline coverage from
physical qualification. [Current CAD notes](../../hardware/cad/CURRENT-NOTES.md),
[print guidance](../../hardware/printing/current/README.md) and the
[guide review summary](../../hardware/build-guide/REVIEW.md) describe current
limitations. Pending source comparisons and physical assembly, acoustic and
full-application qualification must not be represented as completed.

`make hardware-check` verifies offline invariants. Run
`python3 hardware/tools/validation/check.py --publication` for the current strict
build-kit blockers. A pending source comparison is missing evidence, not proof of
a defective part. A successful slice or website deployment does not prove fit.

The Pages workflow requires current-input integrity, a guide build and browser
checks. Pending kit reviews are reported separately in its job summary. Local
[preview](../../hardware/build-guide/README.md#build-and-preview) remains available
independently of website deployment and physical qualification.

## Privacy and metadata

Review the intended public files and Git history, including native metadata,
images and packaged downloads. A clean working tree does not sanitize history.
Keep private legacy refs out of public pushes. If a credential is exposed, rotate
it; deleting a file or repository does not invalidate the credential.

Bambu projects and generated downloads must have no nonempty `DesignerUserId`.
The packaging check enforces that narrow rule; it is not a general privacy audit.
The [privacy proof](../../hardware/printing/recipes/project-privacy.json) records
the metadata-only sanitization. Native CAD may retain application resource paths;
review native metadata deliberately and avoid byte edits that corrupt the file or
invalidate accepted input hashes.

## License coverage

[LICENSING.md](../../LICENSING.md) defines the license grants and every
exception, and the guide footer credits the third-party material the guide
uses. Publisher reference documents are linked externally, not bundled with the
source or generated guide. Original project templates remain included.

### Dance song

The project soundtrack and its beat and light data are included under the
[separate soundtrack notice](../../LICENSING.md#project-soundtrack-separate-terms),
not MIT or CC0. The song was generated using ElevenLabs;
`scripts/analyze_beats.py` and `scripts/analyze_song_lights.py` derive the beat
and light data from it. Keep the notice with project packages and Pi
payloads. Source identity and hashes are in
[asset-manifest.json](asset-manifest.json); private licensing correspondence
and billing records are not part of the public repository.

## Dependency notices

Original-code licensing does not relicense dependencies. The source package and
Pi payload install dependencies separately rather than bundling a Python
environment. A prebuilt image requires a review of its exact binaries, embedded
libraries, notices and corresponding-source obligations.

Known notice considerations for the inspected dependency versions include:

- SoXR/libsoxr: LGPL-2.1-or-later in the inspected 1.1.0 distribution.
- Certifi and development dependency pathspec: MPL-2.0.
- `ring-doorbell`, used only by the optional Ring setup helper: LGPL-3.0.
  Optional beat-analysis tools need their own review and remain outside the Pi
  runtime environment.
- rpi-ws281x 5.0.0: BSD-2-Clause in its source license texts despite MIT package metadata.
- Selected pigpiod v79 source: Unlicense; retain its supplied notice.

Data from TMDB, JustWatch (through TMDB) and Watchmode, used by the optional
streaming feature, requires attribution; the
[README](../../README.md#safety-and-license) gives it.

This list does not exhaustively cover Pi OS or all ARM and optional helper
binaries. Review resolved versions when redistributing a prebuilt environment.

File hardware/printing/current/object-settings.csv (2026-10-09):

plate | plate_id | part | label | layer_height | wall_loops | sparse_infill_density | sparse_infill_pattern | brim_type | brim_width | brim_object_gap | enable_support | support_type | support_style | support_top_z_distance | support_bottom_z_distance | support_object_xy_distance | outer_wall_speed | inner_wall_speed | initial_layer_speed
1 | W1 | P43 | P43-1 | 0.2 | 5 | 25% | gyroid | outer_only | 3 | 0.1 | 0 | tree(auto) | default | 0.2 | 0.2 | 0.35 | 200,350 | 300,400 | 50,50
1 | W1 | P03 | P03-1 | 0.16 | 4 | 25% | gyroid | outer_only | 3 | 0.1 | 1 | tree(auto) | default | 0.2 | 0.2 | 0.4 | 200,350 | 300,400 | 50,50
1 | W1 | P04 | P04-1 | 0.16 | 5 | 25% | gyroid | outer_only | 3 | 0.1 | 1 | tree(auto) | default | 0.2 | 0.2 | 0.4 | 200,350 | 300,400 | 50,50
1 | W1 | P06 | P06-1 | 0.2 | 3 | 15% | grid | outer_only | 3 | 0.1 | 0 | tree(auto) | default | 0.2 | 0.2 | 0.35 | 200,350 | 300,400 | 50,50
1 | W1 | P08 | P08-1 | 0.16 | 4 | 20% | grid | outer_only | 3 | 0.1 | 1 | tree(auto) | default | 0.16 | 0.16 | 0.4 | 80,80 | 120,120 | 25,25
1 | W1 | P14 | P14-1 | 0.2 | 3 | 15% | grid | outer_only | 3 | 0.1 | 0 | tree(auto) | default | 0.2 | 0.2 | 0.35 | 200,350 | 300,400 | 50,50
1 | W1 | FB24 | FB24-1 | 0.16 | 4 | 20% | grid | outer_only | 3 | 0.1 | 1 | tree(auto) | default | 0.16 | 0.16 | 0.4 | 80,80 | 120,120 | 25,25
1 | W1 | FB32 | FB32-1 | 0.16 | 4 | 25% | gyroid | outer_only | 3 | 0.1 | 1 | tree(auto) | default | 0.2 | 0.2 | 0.4 | 200,350 | 300,400 | 50,50
2 | K1 | FB01 | FB01-1 | 0.2 | 4 | 25% | gyroid | outer_only | 5 | 0.12 | 1 | normal(auto) | snug | 0.2 | 0.2 | 0.4 | 50,50 | 100,100 | 20,20
2 | K1 | P30 | P30-1 | 0.16 | 5 | 35% | gyroid | outer_only | 5 | 0.12 | 1 | tree(auto) | default | 0.24 | 0.24 | 0.4 | 30 | 50 | 20
2 | K1 | P31 | P31-1 | 0.16 | 5 | 35% | gyroid | outer_only | 5 | 0.12 | 1 | tree(auto) | default | 0.24 | 0.24 | 0.4 | 30 | 50 | 20
3 | W2 | P02 | P02-1 | 0.2 | 3 | 15% | grid | outer_only | 3 | 0.1 | 0 | tree(auto) | default | 0.2 | 0.2 | 0.35 | 200,350 | 300,400 | 50,50
3 | W2 | P06 | P06-1 | 0.2 | 3 | 15% | grid | outer_only | 3 | 0.1 | 0 | tree(auto) | default | 0.2 | 0.2 | 0.35 | 200,350 | 300,400 | 50,50
3 | W2 | P09 | P09-1 | 0.2 | 3 | 15% | grid | outer_only | 3 | 0.1 | 1 | tree(auto) | default | 0.2 | 0.2 | 0.35 | 200,350 | 300,400 | 50,50
3 | W2 | P09 | P09-2 | 0.2 | 3 | 15% | grid | outer_only | 3 | 0.1 | 1 | tree(auto) | default | 0.2 | 0.2 | 0.35 | 200,350 | 300,400 | 50,50
3 | W2 | P10 | P10-1 | 0.16 | 4 | 25% | gyroid | outer_only | 3 | 0.12 | 0 | normal(auto) | snug | 0.2 | 0.2 | 0.4 | 30 | 50 | 20,20
3 | W2 | P10 | P10-2 | 0.16 | 4 | 25% | gyroid | outer_only | 3 | 0.12 | 0 | normal(auto) | snug | 0.2 | 0.2 | 0.4 | 30 | 50 | 20,20
3 | W2 | P10 | P10-3 | 0.16 | 4 | 25% | gyroid | outer_only | 3 | 0.12 | 0 | normal(auto) | snug | 0.2 | 0.2 | 0.4 | 30 | 50 | 20,20
3 | W2 | P11 | P11-1 | 0.2 | 4 | 25% | gyroid | outer_only | 3 | 0.1 | 1 | tree(auto) | default | 0.2 | 0.2 | 0.35 | 200,350 | 300,400 | 50,50
3 | W2 | P42 | P42-1 | 0.2 | 4 | 25% | gyroid | outer_only | 3 | 0.1 | 1 | tree(auto) | default | 0.2 | 0.2 | 0.35 | 200,350 | 300,400 | 50,50
3 | W2 | P12 | P12-1 | 0.2 | 4 | 25% | gyroid | outer_only | 3 | 0.1 | 1 | tree(auto) | default | 0.2 | 0.2 | 0.35 | 200,350 | 300,400 | 50,50
3 | W2 | P34 | P34-1 | 0.2 | 4 | 25% | gyroid | outer_only | 3 | 0.1 | 1 | tree(auto) | default | 0.2 | 0.2 | 0.4 | 200,350 | 300,400 | 50,50
3 | W2 | P35 | P35-1 | 0.16 | 4 | 25% | gyroid | outer_only | 5 | 0.12 | 1 | normal(auto) | snug | 0.2 | 0.2 | 1.35 | 40 | 60 | 20,20
4 | C1 | AR01 | AR01-1 | 0.16 | 5 | 35% | gyroid | outer_only | 5 | 0.12 | 1 | tree(auto) | default | 0.24 | 0.24 | 0.4 | 30,30 | 50,50 | 25,25
4 | C1 | AR04 | AR04-1 | 0.16 | 5 | 35% | gyroid | outer_only | 8 | 0.08 | 1 | tree(auto) | default | 0.24 | 0.24 | 0.4 | 25,25 | 40,40 | 20,20
4 | C1 | P01 | P01-1 | 0.16 | 5 | 35% | gyroid | outer_and_inner | 8 | 0.08 | 1 | tree(auto) | default | 0.24 | 0.24 | 0.4 | 25,25 | 40,40 | 20,20
4 | C1 | P01 | P01-2 | 0.16 | 5 | 35% | gyroid | outer_and_inner | 8 | 0.08 | 1 | tree(auto) | default | 0.24 | 0.24 | 0.4 | 25,25 | 40,40 | 20,20
4 | C1 | GS11 | GS11-1 | 0.16 | 5 | 35% | gyroid | outer_only | 8 | 0.08 | 1 | tree(auto) | default | 0.24 | 0.24 | 0.4 | 25,25 | 40,40 | 20,20
4 | C1 | GS12 | GS12-1 | 0.16 | 5 | 35% | gyroid | outer_only | 8 | 0.08 | 1 | tree(auto) | default | 0.24 | 0.24 | 0.4 | 25,25 | 40,40 | 20,20
5 | B1 | AR02 | AR02-1 | 0.16 | 5 | 35% | gyroid | outer_only | 5 | 0.12 | 1 | tree(auto) | default | 0.24 | 0.24 | 0.4 | 30,30 | 50,50 | 50,50
5 | B1 | AR05 | AR05-1 | 0.16 | 5 | 35% | gyroid | outer_only | 5 | 0.12 | 1 | tree(auto) | default | 0.24 | 0.24 | 0.4 | 30,30 | 50,50 | 50,50
5 | B1 | AR03 | AR03-1 | 0.16 | 5 | 35% | gyroid | outer_only | 5 | 0.12 | 1 | tree(auto) | default | 0.24 | 0.24 | 0.4 | 30,30 | 50,50 | 50,50
5 | B1 | AR06 | AR06-1 | 0.16 | 5 | 35% | gyroid | outer_only | 5 | 0.12 | 1 | tree(auto) | default | 0.24 | 0.24 | 0.4 | 30,30 | 50,50 | 50,50
5 | B1 | AR08 | AR08-1 | 0.12 | 3 | 20% | gyroid | outer_only | 3 | 0.12 | 1 | tree(auto) | default | 0.2 | 0.2 | 0.4 | 30,30 | 50,50 | 50,50
5 | B1 | AR09 | AR09-1 | 0.12 | 3 | 20% | gyroid | outer_only | 3 | 0.12 | 1 | tree(auto) | default | 0.2 | 0.2 | 0.4 | 30,30 | 50,50 | 50,50
5 | B1 | A04 | A04-1 | 0.16 | 4 | 25% | gyroid | outer_only | 4 | 0.1 | 1 | tree(auto) | default | 0.2 | 0.2 | 0.6 | 30 | 50 | 20,20
6 | B2 | GS20 | GS20-1 | 0.16 | 4 | 20% | grid | outer_only | 3 | 0.1 | 1 | tree(auto) | default | 0.16 | 0.16 | 0.4 | 60,60 | 120,120 | 25,25
7 | C2 | FB03 | FB03-1 | 0.16 | 4 | 25% | gyroid | outer_only | 3 | 0.1 | 1 | tree(auto) | default | 0.16 | 0.16 | 0.4 | 40,40 | 80,80 | 25,25
7 | C2 | FB19 | FB19-1 | 0.16 | 4 | 25% | gyroid | outer_only | 3 | 0.1 | 1 | tree(auto) | default | 0.16 | 0.16 | 0.4 | 40,40 | 80,80 | 25,25
7 | C2 | FB19 | FB19-2 | 0.16 | 4 | 25% | gyroid | outer_only | 3 | 0.1 | 1 | tree(auto) | default | 0.16 | 0.16 | 0.4 | 40,40 | 80,80 | 25,25
7 | C2 | FB20 | FB20-1 | 0.16 | 4 | 25% | gyroid | outer_only | 3 | 0.1 | 1 | tree(auto) | default | 0.16 | 0.16 | 0.4 | 40,40 | 80,80 | 25,25
7 | C2 | FB21 | FB21-1 | 0.16 | 4 | 25% | gyroid | outer_only | 3 | 0.1 | 1 | tree(auto) | default | 0.16 | 0.16 | 0.4 | 40,40 | 80,80 | 25,25
7 | C2 | FB41 | FB41-1 | 0.16 | 4 | 25% | gyroid | outer_only | 3 | 0.1 | 1 | tree(auto) | default | 0.16 | 0.16 | 0.4 | 40,40 | 80,80 | 25,25
7 | C2 | P36 | P36-1 | 0.16 | 4 | 25% | gyroid | outer_only | 3 | 0.1 | 1 | tree(auto) | default | 0.16 | 0.16 | 0.4 | 40,40 | 80,80 | 25,25
7 | C2 | P36 | P36-2 | 0.16 | 4 | 25% | gyroid | outer_only | 3 | 0.1 | 1 | tree(auto) | default | 0.16 | 0.16 | 0.4 | 40,40 | 80,80 | 25,25
7 | C2 | P38 | P38-1 | 0.16 | 4 | 25% | gyroid | outer_only | 3 | 0.1 | 1 | tree(auto) | default | 0.16 | 0.16 | 0.4 | 40,40 | 80,80 | 25,25
7 | C2 | P39 | P39-1 | 0.16 | 4 | 25% | gyroid | outer_only | 3 | 0.1 | 1 | tree(auto) | default | 0.16 | 0.16 | 0.4 | 40,40 | 80,80 | 25,25
7 | C2 | P40 | P40-1 | 0.16 | 4 | 25% | gyroid | outer_only | 3 | 0.1 | 1 | tree(auto) | default | 0.16 | 0.16 | 0.4 | 40,40 | 80,80 | 25,25
8 | G1 | B01 | B01-1 | 0.16 | 3 | 20% | grid | outer_only | 3 | 0.12 | 1 | normal(auto) | snug | 0.2 | 0.2 | 1.35 | 40,40 | 60,60 | 50,50
8 | G1 | B02 | B02-1 | 0.16 | 3 | 20% | grid | outer_only | 3 | 0.12 | 1 | normal(auto) | snug | 0.2 | 0.2 | 1.35 | 40,40 | 60,60 | 50,50
8 | G1 | B02 | B02-2 | 0.16 | 3 | 20% | grid | outer_only | 3 | 0.12 | 1 | normal(auto) | snug | 0.2 | 0.2 | 1.35 | 40,40 | 60,60 | 50,50
8 | G1 | B02 | B02-3 | 0.16 | 3 | 20% | grid | outer_only | 3 | 0.12 | 1 | normal(auto) | snug | 0.2 | 0.2 | 1.35 | 40,40 | 60,60 | 50,50
8 | G1 | B02 | B02-4 | 0.16 | 3 | 20% | grid | outer_only | 3 | 0.12 | 1 | normal(auto) | snug | 0.2 | 0.2 | 1.35 | 40,40 | 60,60 | 50,50
8 | G1 | B03 | B03-1 | 0.16 | 3 | 20% | grid | outer_only | 3 | 0.12 | 1 | normal(auto) | snug | 0.2 | 0.2 | 1.35 | 40,40 | 60,60 | 50,50
8 | G1 | B04 | B04-1 | 0.16 | 3 | 20% | grid | outer_only | 3 | 0.12 | 1 | normal(auto) | snug | 0.2 | 0.2 | 1.35 | 40,40 | 60,60 | 50,50
8 | G1 | B09 | B09-1 | 0.16 | 3 | 20% | grid | outer_only | 3 | 0.12 | 1 | normal(auto) | snug | 0.2 | 0.2 | 1.35 | 40,40 | 60,60 | 50,50
8 | G1 | B09 | B09-2 | 0.16 | 3 | 20% | grid | outer_only | 3 | 0.12 | 1 | normal(auto) | snug | 0.2 | 0.2 | 1.35 | 40,40 | 60,60 | 50,50
8 | G1 | B09 | B09-3 | 0.16 | 3 | 20% | grid | outer_only | 3 | 0.12 | 1 | normal(auto) | snug | 0.2 | 0.2 | 1.35 | 40,40 | 60,60 | 50,50
8 | G1 | B09 | B09-4 | 0.16 | 3 | 20% | grid | outer_only | 3 | 0.12 | 1 | normal(auto) | snug | 0.2 | 0.2 | 1.35 | 40,40 | 60,60 | 50,50
8 | G1 | B09 | B09-5 | 0.16 | 3 | 20% | grid | outer_only | 3 | 0.12 | 1 | normal(auto) | snug | 0.2 | 0.2 | 1.35 | 40,40 | 60,60 | 50,50
8 | G1 | B09 | B09-6 | 0.16 | 3 | 20% | grid | outer_only | 3 | 0.12 | 1 | normal(auto) | snug | 0.2 | 0.2 | 1.35 | 40,40 | 60,60 | 50,50
8 | G1 | B09 | B09-7 | 0.16 | 3 | 20% | grid | outer_only | 3 | 0.12 | 1 | normal(auto) | snug | 0.2 | 0.2 | 1.35 | 40,40 | 60,60 | 50,50
8 | G1 | B09 | B09-8 | 0.16 | 3 | 20% | grid | outer_only | 3 | 0.12 | 1 | normal(auto) | snug | 0.2 | 0.2 | 1.35 | 40,40 | 60,60 | 50,50
8 | G1 | GS01 | GS01-1 | 0.16 | 3 | 20% | grid | outer_only | 3 | 0.1 | 1 | tree(auto) | default | 0.16 | 0.16 | 0.4 | 200,350 | 300,400 | 50,50
8 | G1 | GS02 | GS02-1 | 0.16 | 3 | 20% | grid | outer_only | 3 | 0.1 | 1 | tree(auto) | default | 0.16 | 0.16 | 0.4 | 200,350 | 300,400 | 50,50
8 | G1 | GS03 | GS03-1 | 0.16 | 3 | 20% | grid | outer_only | 3 | 0.1 | 1 | tree(auto) | default | 0.16 | 0.16 | 0.4 | 200,350 | 300,400 | 50,50
9 | K2 | FB02 | FB02-1 | 0.2 | 4 | 25% | gyroid | outer_only | 5 | 0.12 | 0 | normal(auto) | snug | 0.2 | 0.2 | 0.4 | 50,50 | 100,100 | 20,20
9 | K2 | P37 | P37-1 | 0.16 | 4 | 25% | gyroid | outer_only | 5 | 0.12 | 0 | normal(auto) | snug | 0.2 | 0.2 | 0.4 | 30 | 50 | 20,20
9 | K2 | P37 | P37-2 | 0.16 | 4 | 25% | gyroid | outer_only | 5 | 0.12 | 0 | normal(auto) | snug | 0.2 | 0.2 | 0.4 | 30 | 50 | 20,20
10 | T1 | A05 | A05-1 | 0.16 | 3 | 15% | grid | outer_only | 4 | 0.1 | 1 | tree(auto) | default | 0.2 | 0.2 | 0.6 | 60,60 | 100,100 | 50,50

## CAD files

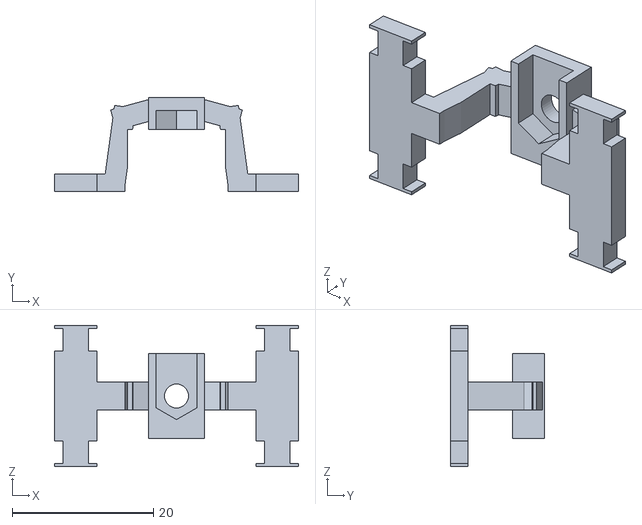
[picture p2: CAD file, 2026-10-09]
hardware/cad/current/stl/P42.stl
34.6 x 13.3 x 20.0

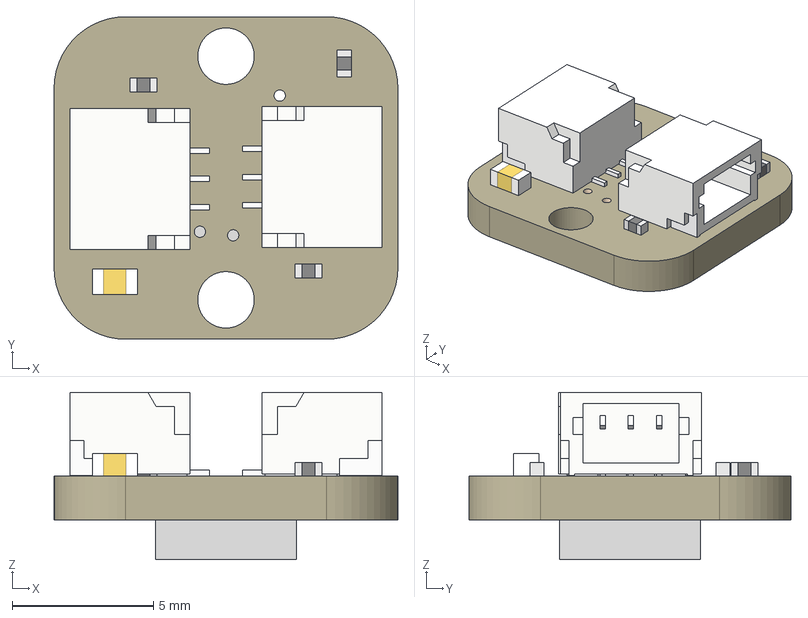
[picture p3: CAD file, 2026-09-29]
hardware/lighting/adafruit-5975/5975-NeoPixel-Breakout.step
12.2 x 11.4 x 5.93 mm
Board
1uF
WS2812B_5050N
JST SH 3P x 2

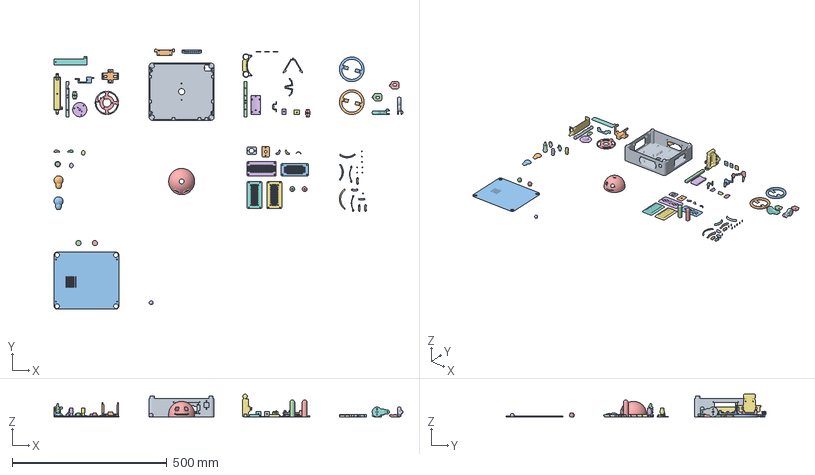
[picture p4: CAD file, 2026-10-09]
hardware/printing/current/BlooglyBlob-R33-PLA-Production.3mf
1126.9 x 840.4 x 73.5 mm
P43-1 | White | R33
P03-1 | White
P04-1 | White | R33
P06-1 | White x 2
P08-1 | White
P14-1 | White
FB24-1 | White
FB32-1 | White
FB01-1 | Black
P30-1 | Black
P31-1 | Black
P02-1 | White
P09-1 | White
P09-2 | White
P10-1 | White
P10-2 | White
P10-3 | White
P11-1 | White | R33
P42-1 | White | R33
P12-1 | White | R33
P34-1 | White
P35-1 | White
AR01-1 | Copper
AR04-1 | Copper
P01-1 | Copper
P01-2 | Copper
GS11-1 | Copper
GS12-1 | Copper
AR02-1 | Blue
AR05-1 | Blue
AR03-1 | Blue
AR06-1 | Blue
AR08-1 | Blue
AR09-1 | Blue
A04-1 | Blue
GS20-1 | Blue
FB03-1 | Copper
FB19-1 | Copper
FB19-2 | Copper
FB20-1 | Copper
FB21-1 | Copper
FB41-1 | Copper
P36-1 | Copper
P36-2 | Copper
P38-1 | Copper
P39-1 | Copper
P40-1 | Copper
B01-1 | Gray
B02-1 | Gray
B02-2 | Gray
B02-3 | Gray
B02-4 | Gray
B03-1 | Gray
B04-1 | Gray
B09-1 | Gray
B09-2 | Gray
B09-3 | Gray
B09-4 | Gray
B09-5 | Gray
B09-6 | Gray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

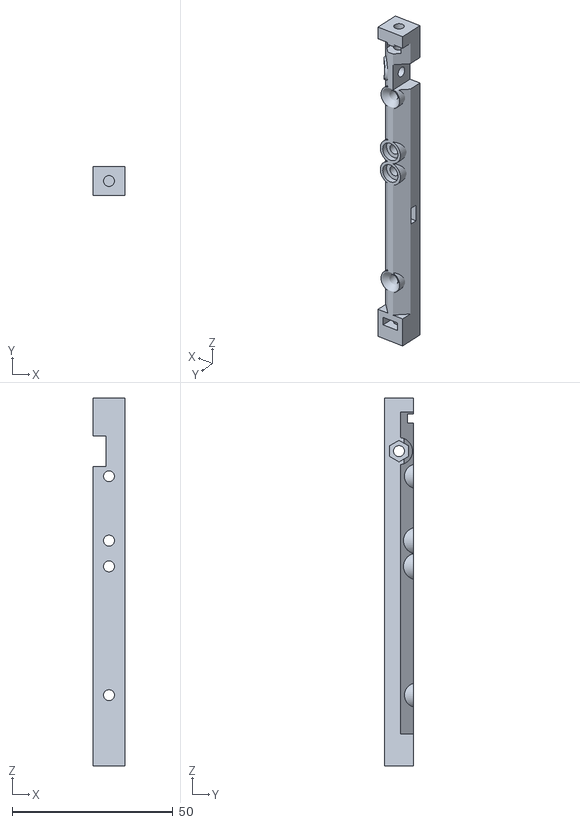
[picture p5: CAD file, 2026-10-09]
hardware/cad/current/stl/P43.stl
10.0 x 9.00 x 114.3

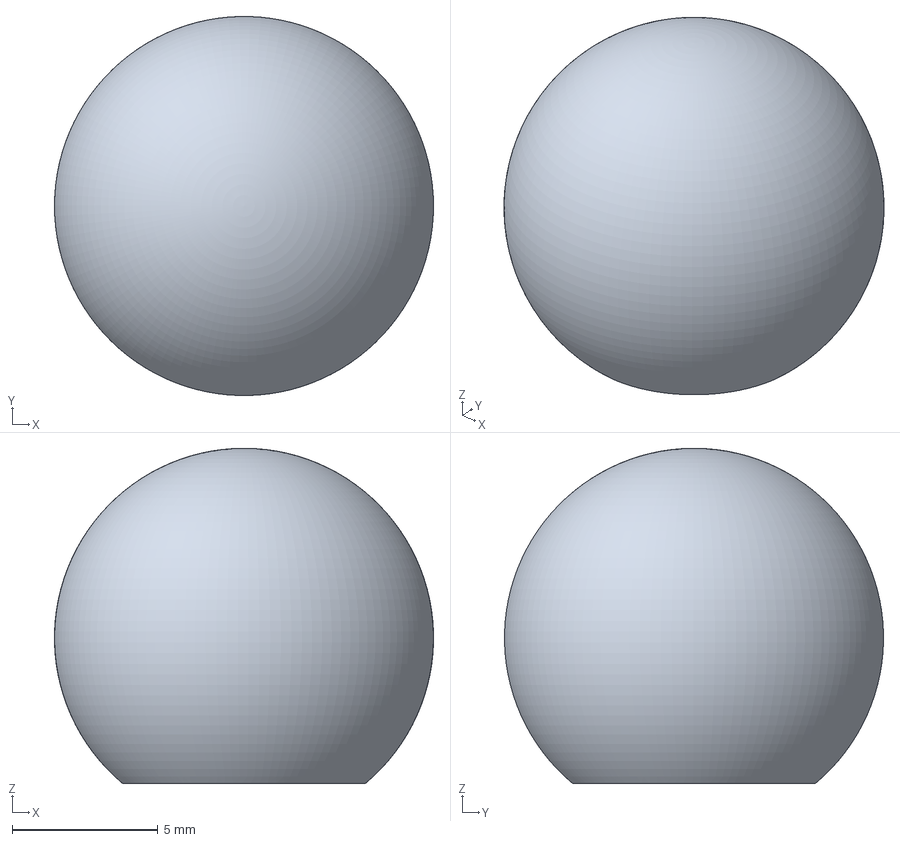
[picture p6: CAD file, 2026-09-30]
hardware/printing/current/BlooglyBlob-R29-Optional-Clear-PETG-Ball.3mf
13.0 x 13.0 x 11.5 mm

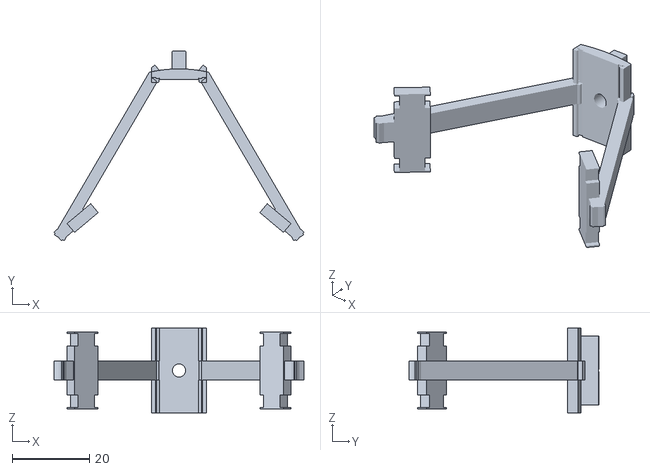
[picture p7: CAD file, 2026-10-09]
hardware/cad/current/stl/P12.stl
64.8 x 49.2 x 22.0

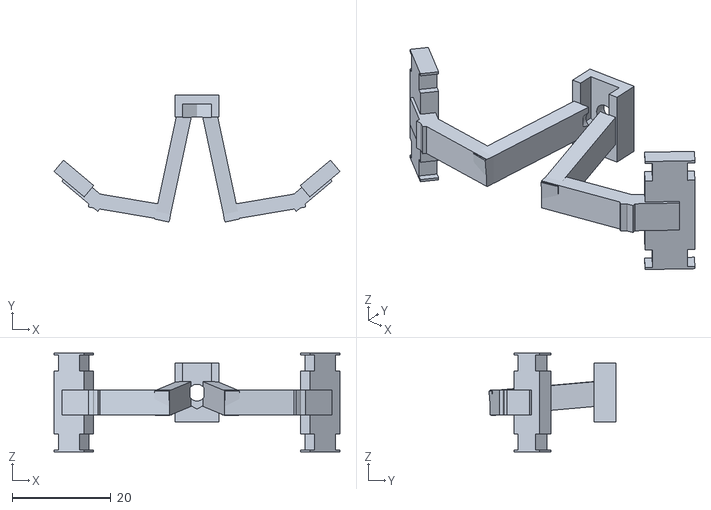
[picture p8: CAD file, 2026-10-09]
hardware/cad/current/stl/P11.stl
58.0 x 25.8 x 20.0

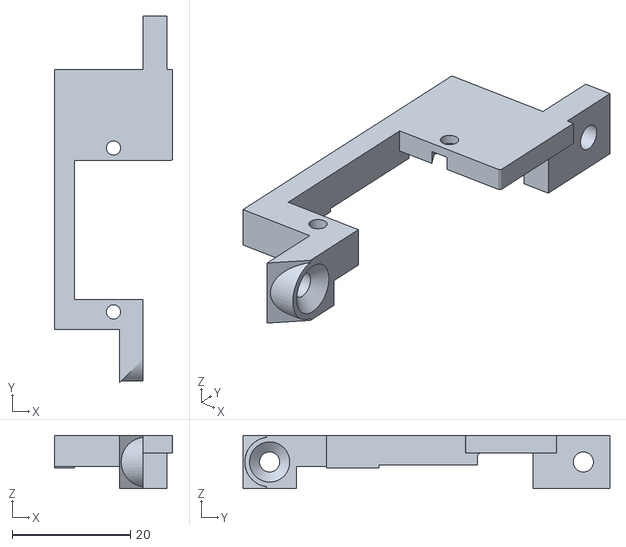
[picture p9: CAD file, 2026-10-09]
hardware/cad/current/stl/P04.stl
20.0 x 62.0 x 9.00

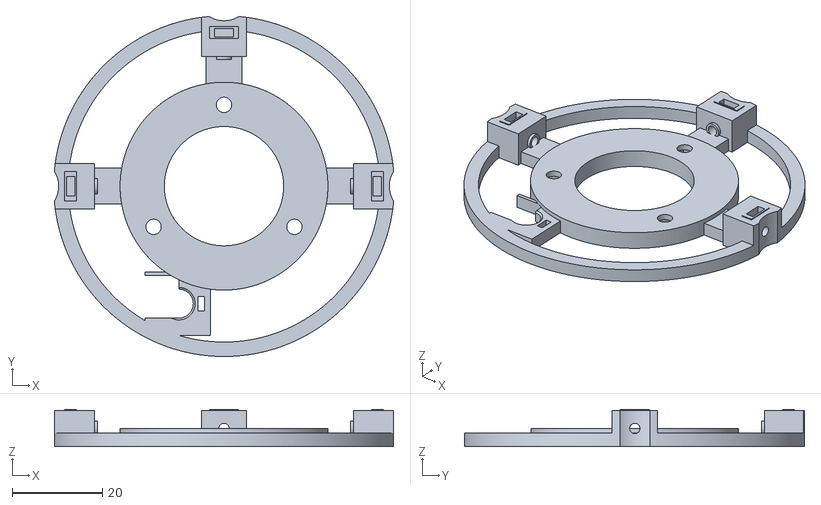
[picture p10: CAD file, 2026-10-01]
hardware/cad/current/stl/P08.stl
75.1 x 75.3 x 8.20

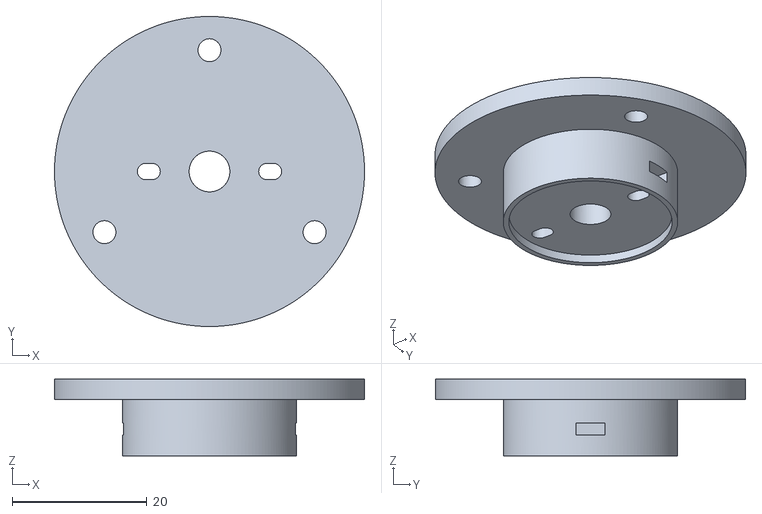
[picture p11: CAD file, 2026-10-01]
hardware/cad/current/stl/P14.stl
46.0 x 46.0 x 11.4

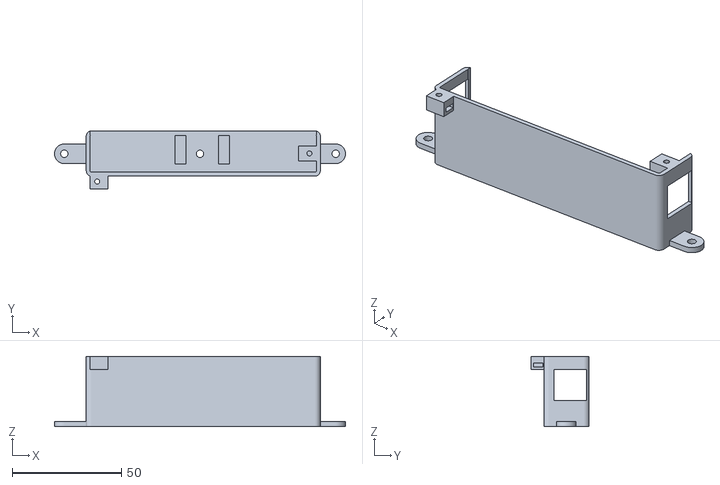
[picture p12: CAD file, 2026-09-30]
hardware/cad/current/stl/FB24.stl
133.0 x 26.7 x 32.0

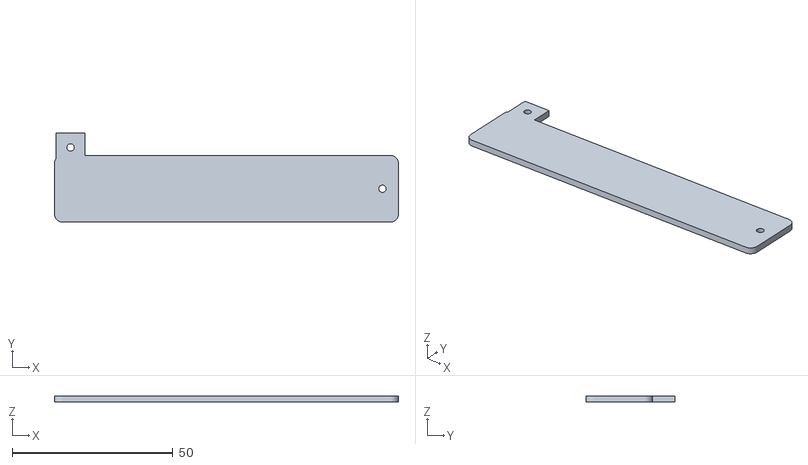
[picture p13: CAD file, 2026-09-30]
hardware/cad/current/stl/FB32.stl
107.0 x 27.7 x 2.00

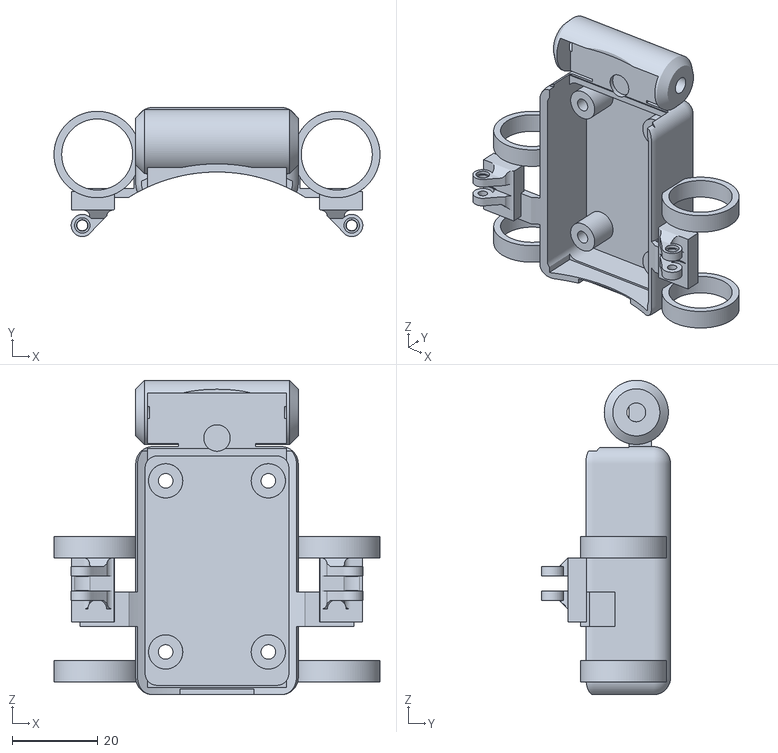
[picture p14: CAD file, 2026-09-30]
hardware/cad/current/stl/P35.stl
76.2 x 30.2 x 73.5

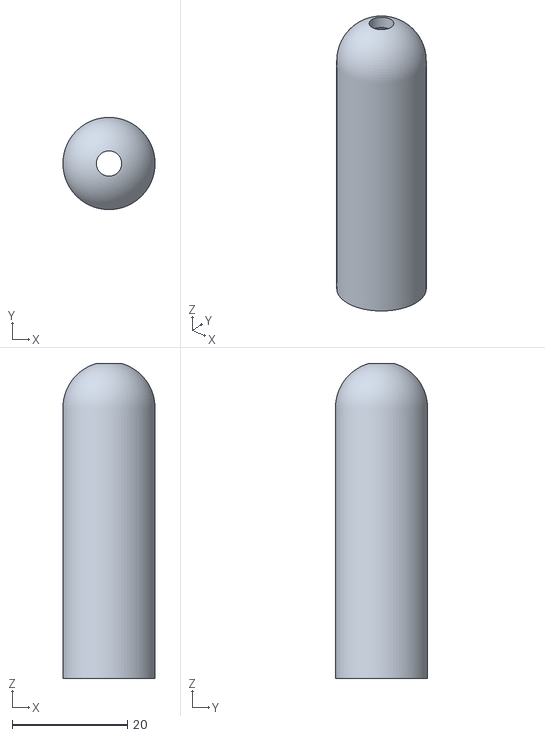
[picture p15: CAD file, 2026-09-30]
hardware/cad/current/stl/P36.stl
16.0 x 16.0 x 54.7

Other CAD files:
hardware/cad/current/stl/A04.stl
hardware/cad/current/stl/P06.stl
hardware/cad/current/stl/AR09.stl
hardware/cad/current/stl/P38.stl
hardware/cad/current/assembly.f3d
hardware/cad/current/stl/A05.stl
hardware/cad/current/stl/AR01.stl
hardware/cad/current/stl/AR02.stl
hardware/cad/current/stl/AR03.stl
hardware/cad/current/stl/AR04.stl
hardware/cad/current/stl/AR05.stl
hardware/cad/current/stl/AR06.stl
hardware/cad/current/stl/AR07.stl
hardware/cad/current/stl/AR08.stl
hardware/cad/current/stl/B01.stl
hardware/cad/current/stl/B02.stl
hardware/cad/current/stl/B03.stl
hardware/cad/current/stl/B04.stl
hardware/cad/current/stl/B09.stl
hardware/cad/current/stl/FB01.stl
hardware/cad/current/stl/FB02.stl
hardware/cad/current/stl/FB03.stl
hardware/cad/current/stl/FB19.stl
hardware/cad/current/stl/FB20.stl
hardware/cad/current/stl/FB21.stl
hardware/cad/current/stl/FB26.stl
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

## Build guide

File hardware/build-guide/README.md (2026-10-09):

# Build guide authoring

Start with the [hardware workflow](../README.md). There is one authored guide,
`src/`, versioned in ordinary Git. `dist/` is ignored build output. The guide
consumes selected CAD, print, assembly and reference inputs when built; the CAD
registry and delivery do not pin guide content. Public assembly instructions
belong in the guide; contributor workflow and readiness evidence belong here or
in the [current review summary](REVIEW.md). Detailed working notes stay private.

## Build and preview

Use Python 3.12 or 3.13 from the repository root:

```sh
make hardware-check
make guide-build
python3 -m http.server 8769 --bind 127.0.0.1 --directory hardware/build-guide/dist
```

Keep the preview at [http://127.0.0.1:8769](http://127.0.0.1:8769) so browser
progress remains available. Preview builds can be useful while publication is
blocked; a successful build is not publication approval. A validated build replaces
the preview; an interrupted swap retains an ignored `.guide-previous/` backup
that the next build restores before checking inputs.

The builder copies authored content and derives data/downloads from their own
homes, without retaining source copies in the guide:

- Required and optional STLs selected by the part catalog (excluding retired
  exports), and the exact editable projects selected by the print manifest,
  their object-settings CSV and project thumbnails. ZIP timestamps are fixed for
  reproducible packages. Plate thumbnails show layouts, not sliced toolpaths.
- Assembly power/signal tables and the selected print quantities and estimates.
- Prices from [the price catalog](../catalog/prices.json), combined with current
  part quantities and plate weights. Part cards and `#cost` use this same data;
  do not enter prices or totals directly in guide prose.
- External component-document links selected by the
  [reference catalog](../references/community-20260925/catalog.json). Publisher
  PDFs are not stored in Git or bundled with the guide. Keep optional research
  downloads in ignored `hardware/.work/`; builds never fetch or require them.

The `print-plates` step is the single printing page. `#printing` links redirect there,
including links that locate a particular part’s plate. Plate layouts, individual
STL links and settings expand within that step using the main content of
`src/repeat-build.html`, bundled at build time. Edit that one authored source;
the standalone URL remains available for bookmarks and non-JavaScript readers.
The printing step offers Bambu Studio and other-slicer instructions; the choice
is saved with browser progress. Shared layouts and per-part settings stay available.

It checks package metadata and local references. Keep `src/` limited to authored
pages, text, data, diagrams, templates and pictures; do not add alternate guide
versions, CAD/project copies or copied datasheets.

## Review an input or guide change

Follow the [instruction design guidance](INSTRUCTION-DESIGN.md) for action
illustrations, concise copy, page layout and visual review.

Use `python3 hardware/tools/cad/impact.py PART_ID` to start an impact review, then
cover changed process, hardware, electrical and software dependencies too.
Unknown relationships require review. In the ignored local work record, name each
affected surface and record whether it changed, was reused with unchanged
relevant dependencies, or was reviewed:

- Steps and repeat-build instructions, and step IDs and their links.
- Part/supply/plate cards, fastener allocations, quantities, estimates and downloads.
- Models, diagrams, assembly close-ups, templates and hardware keys.
- Wiring/reference pages, component specifications and software commands.

Prefer bench preparation before installation: solder, insulate, label and check
loose components or harnesses before fastening them to printed parts. Where
length depends on the assembly, test-route and mark first, then return to the
bench for hot work. Finish soldered harnesses before plugging them into mounted
boards; keep final routing, restraint and connector seating in the installation
step. Review access before closing covers or fitting parts that obstruct tools.

Check the assembly meaning visually: mating surfaces, clearances, access and
fastener engagement need review even when a generator succeeds.

Use [review-status.json](review-status.json) as a manual release checklist and
[REVIEW.md](REVIEW.md) for concise public evidence and limitations.
After changing the guide or its inputs, mark affected sections pending. Before
publication, inspect those sections against the intended release revision and
record `reviewed_revision`, reviewer and evidence. The checker validates the
checklist entries; it does not infer freshness or perform the human review.
There is no automatic fingerprint or repository-wide dependency graph.

To test the guide with builders who have not seen it, use the
[cold-reader test protocol](COLD-READER-PROTOCOL.md).

`consistency.py check` checks quantities, references and documented commands.
Pending manual review permits local previews. `consistency.py check --publication`
also requires the release checklist; it does not establish physical fit.

## Optional authoring tools

The main robot image (`src/assets/r22/main-front.png`, retaining its existing URL)
starts with a native Fusion **Design workspace, Shaded** capture, with masked
LED lighting and raised black screw heads added to the visible vents and button
plate. Its source hash, camera, export settings and image edits are recorded in
[presentation-front.json](../rendering/presentation-front.json).
Import the selected `assembly.f3d` into a separate presentation document, retain
its appearances and visibility, and export an antialiased transparent PNG with
those settings. Do not save changes to MAIN. Apply lighting within the existing
diffuser boundaries, preserve the mouth shape and alpha channel, and align screw
heads with the existing holes. The glow illustrates illumination; it is not an
optical simulation. The committed PNG is the finished presentation asset;
ordinary builds do not require the local image-editing tools. Review it in the
guide and rerun `make guide-social-card` after replacing it. The assembly
illustration generator deliberately leaves this image alone.

The homepage adds decorative lighting with `src/hero-motion.js` and five
committed images in `src/assets/hero/`. Their source and hashes are recorded in
the same presentation record. Ordinary guide checks verify the committed asset
hashes. The base and canvas retain the still image’s 1400 × 1600 resolution. The animation uses
the original diffuser masks; keep these registered with the base image when
replacing it. Only the homepage
animates: assembly steps, the README, enlarged views and the social card retain
the still image. The reader can pause or play; reduced-motion preferences show
the still by default. Animation stops outside the viewport, in hidden tabs and
when leaving the page. Image-loading failure also leaves the still visible. The
control retains keyboard focus during loading and offers a retry on failure. Glow uses canvas compositing
without depending on browser-specific canvas filters.
No audio input, device connection, new dependency or image-generation tool is
needed to run or build the animation.

Ordinary checking/building uses committed authored assets. These generators need
additional local tools only when changing those assets; review generated diffs:

- `hardware/tools/guide/render_models.py` renders CAD views and front-fastening
  sections. Install NumPy, Pillow, Numba and trimesh, and supply a licensed local
  TrueType font. Render for review with
  `python3 hardware/tools/guide/render_models.py --output hardware/.work/guide/UNIQUE-RUN --font /path/to/font.ttf`.
  The output directory must be new; add `--write` only to adopt reviewed images
  into `src/`. Source identity and scene/dimension review gates must pass for the
  selected CAD revision; do not bypass them to force new pictures.
- `hardware/tools/guide/render_hand_arm_actions.py --output NEW_DIR --font FONT`
  renders magnet, horn and strap installation close-ups from the same checked
  CAD source. It checks the receiving features before drawing nominal magnets and
  drilled horns, and records source hashes and dimensions. Inspect scratch images
  before using `--write`. Broad model rendering also applies these action views
  whenever their public paths are selected, so it cannot restore empty-seat views.
- `hardware/tools/guide/diagrams.py` writes schematic SVGs into `src/assets/`.
- `hardware/tools/guide/master_wiring.py --out PATH.svg` draws the complete wiring
  reference. Review its terminal assignments against `hardware/assembly/electrical.json`
  and the lighting steps before adopting `src/assets/circuits/master-wiring.svg`.
  Each component appears once; draw continuous wires between registered terminals.
- `hardware/tools/guide/cartoons.py` draws purchased-part, consumable, fastener
  and tool illustrations. Use `--out DIR` for review and naming IDs for a subset.
  Use product drawings/photos as references, consistent projection and scale,
  and do not store product photos in the repository.
- `hardware/tools/guide/make_downloads.py` generates film, foam and screw-key
  PDF templates. It requires `rsvg-convert`.
- `make guide-social-card` renders the link-preview image `src/social-card.png`
  (1200 × 630) from `hardware/tools/guide/social-card.html`, and the robot mark as
  the opaque 180 × 180 `src/apple-touch-icon.png`, with the browser-check
  Playwright install. Every page's Open Graph and X card tags point
  at it by its absolute Pages URL; `test_social_card.py` checks them. Sites cache
  previews, so a changed card may take a while to appear on already-shared links.

## Browser verification and progress

Install Node.js 22 or newer, then the pinned browser-test dependencies:

```sh
make guide-setup
make guide-browser
```

On Linux, use `make guide-setup GUIDE_SYSTEM_DEPS=1` when Chromium system
packages also need installing. Setup is separate from offline checks.

`make guide-browser` builds the guide and starts its own temporary loopback server; an
existing preview is not required or interrupted. Set `BGB_CHROME` to use a local
Chrome executable instead of the downloaded Chromium. Reports go to a new
ignored `hardware/.work/guide/browser-*/` directory.

The check uses an isolated context, visits desktop/mobile routes, checks local
links/images and checks that saved progress is read without migration. Inspect its report and screenshots
for assembly meaning as well as layout. It does not change your browser data.

Progress is saved in the reader's browser under `blooglyblob-guide`. Step IDs are
descriptive slugs such as `board-cover-nuts`, and displayed numbers follow build
order. There is no migration layer: when a step is renamed, split or removed,
saved ticks for its old ID stay stored but no longer count, because progress
counts only current build steps. Update every `{step:…}` reference, `#step-…`
link and part `steps` list when a step ID changes.

## Publication readiness

Website checks and build-kit qualification are separate. Before an authorized
website deployment, run `python3 scripts/check_pages.py` and `make guide-browser`.
These require current-input integrity, a successful build and browser checks;
pending qualification reviews remain visible in the job summary.

Before claiming a qualified build kit, run
`python3 hardware/tools/validation/check.py --publication` and complete the
manual release checklist and affected visual/assembly review against the same
inputs. See [REVIEW.md](REVIEW.md) and the
[release checklist](../../docs/release/checklist.md) for current limitations and
qualification scope. Passing software checks does not establish physical fit.

Documented commands are checked during ordinary builds too. `make pi-servo-fit`
and startup share the fixed fit/rest positions; movement remains within
1000–2000 µs at 50 Hz. See [software validation](../../docs/software/validation.md).
Do not invoke hardware merely to check that a command exists.

Deployment uses [the Pages workflow](../../.github/workflows/guide-pages.yml),
with repository Settings → Pages → Source set to "GitHub Actions". Contributor
checks do not themselves authorize deployment. Keep preview, deployment and
physical qualification distinct when reporting completion.

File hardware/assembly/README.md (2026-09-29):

# Assembly requirements

The [build guide](../build-guide/README.md) contains the maintained assembly
instructions. Structured inputs here provide one source for shared engineering
facts:

- [hardware.json](hardware.json): fastener and purchased-hardware allocations.
- [electrical.json](electrical.json): power and signal tables, read directly by
  the guide builder.
- [interfaces.json](interfaces.json): mating relationships and review requirements.

Change these inputs with the affected CAD/print/guide review described in the
[hardware workflow](../README.md). Keep specifications, installed quantities and
physical observations distinct; do not copy the tables into a competing guide.

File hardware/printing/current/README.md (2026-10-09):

# Editable print recipes

The current CAD is **R33 / Fusion cloud30**, with ten color/material plates,
70 required pieces / 52 types. Open **BlooglyBlob-R33-PLA-Production.3mf** in
Bambu Studio 2.7.1.62. The optional clear PETG ball project replaces A05 on T1.
Logical filament numbers are profiles, not physical AMS slot assignments.

Package estimate: **38h 58m 13s, 680.72 g**. W1 and W2 were freshly
sliced for this update; eight unchanged plates retain their prior estimates.
These are slicer predictions. The unchanged K1 enclosure estimate remains
12h 14m 24s / 289.52 g.

All 71 required/optional source-instance comparisons pass exact triangle and
closed-topology checks. Physical qualification remains separate; use
`python3 hardware/tools/validation/check.py --publication` for current blockers.
See [current review](checks/r33-lighting-validation.json).

## R33 lighting and head carrier

W1 contains P43 FRONT upright and reinforced P04 carrier. W2 contains the
unchanged P02 REAR upright, P11 LOWER, P42 UPPER and P12 MIDDLE light brackets.
Each is quantity 1. P13 front wire guide is retired. P41 is a historical grille
identity and must not be used for the front upright. The P10 foam seam covers
remain unchanged. Historical recipe instance IDs are preserved; explicit part
IDs in the manifest and catalog identify the new parts.

P43 prints rear face down with countersinks up: 0.20 mm layers, 5 walls, 25% gyroid,
supports off. P04 prints servo-seat face down: 0.16 mm, 5 walls, 25% gyroid; automatic
trees remain enabled but this slice generates no carrier support. Both use a
3 mm outer brim with 0.1 mm gap. The carrier's horizontal screw bores bridge;
check bridging and nut fit after cleanup. The front post's M3×10 countersunk
screw is nominal design sizing, not an owner-confirmed installed length; check
full nut engagement. Rear M3×20 remains unchanged.

P11/P42/P12 print upright with accessible nut-entry openings: 0.20 mm layers,
4 walls, 25% gyroid, 3 mm outer brim / 0.1 mm gap, automatic trees with 0.20 mm Z and
0.35 mm XY separation. Lower/upper inset nut-entry and mounting-bore support
samples are clear. Accessible supports remain below arms/pads and in the middle
bracket bore. Hold the arms while clipping supports; avoid twisting the pads.
White PLA profiles stay 220°C nozzle / 55°C textured bed / 12 mm³/s.

The lower and middle brackets are spaced apart on W2; its rear upright moves
6 mm inward to give the brim clearance from the excluded bed corner. All other
objects retain their geometry, process and placement; existing support blockers
are preserved. The retained head opening and screw-bore support cores were
reviewed again. See the [first layers](checks/r33-first-layer.png),
[support review](checks/r33-support-review.png) and
[carrier layers](checks/r33-carrier-layers.png).

## Retained source mesh reconciliation

The downloadable STLs and all 71 required/optional normal meshes now agree
triangle-for-triangle in independently reviewed frames. Forty-one retained recipe
instances were normalized without changing their print settings, orientation,
placement or support modifiers. A04 uses a closed native STL export from the
unchanged R29 design. P08/P14 also use clean direct-native exports of the unchanged R29 bodies. Other selected sources are retained.

Belt supports remain in open clevis gaps and beneath raised hinge ears; the
sampled 1.0 mm pin cores through solid knuckles are clear. Support the ears while
clearing those gaps before inserting pins. Full-height blocker envelopes are not
a promise that every open gap contains no support. Physical cleanup and fit still
need checking.

## Head export stability

P08/P14 use clean native exports of the same R29 geometry. The previous P08
mesh could slice with an unintended cap across its center opening after a tiny
placement change. The replacement passed seven shifted head-pair slices, a fresh
desktop slice and full W1 review. Settings, orientation, blockers and screw
locations are unchanged. Review the opening in Preview after slicing; exact
source matching alone does not establish closed topology or slicer stability.
See checks/r29-head-topology-validation.json for scope and limits.

## R29 changes and cleanup

P08 and P14 use the new three-screw pattern. Fit them together on the bench
with the head and mouth removed. FB24 and FB32 provide the wider USB entrance
and moved left lid fastener; print them as a matched pair. P35 and both P36
canisters omit the inaccessible tank screw/nut features. Bond the hidden
tank-to-ring contact surfaces and the existing elbow/nozzle joints; the complete
backpack remains removable. Individual tanks become permanent.

Five localized support blockers keep the underside P08 nut pockets and the moved
audio lid nut slot/bore open. Inspect the small bridge roofs and clear stray
threads before seating nuts. Accessible supports remain around the audio ends
and in the backpack hinge gaps; support the ears while removing them. Do not
cut the intentionally closed cradle tie slits or the now-filled tank screw holes.

## Audio cradle and backpack cleanup

The closed cradle tie slits are solid design material; do not cut them back open.
Remove ordinary end supports without gouging the tape-facing rear wall or bearing
surfaces. Tape under 1 mm bonds the dongle rear face to the inside rear cradle wall,
not the deck or lid. Actual tape bond and USB connector/end-window fit are still
unqualified. Keep the bare-module-first and actual-connector-fit checks in the guide.

The backpack pin-seat cores remain clear in sampled paths, while
support remains in the open hinge gap. Support the ears
while cleaning those regions before inserting pins. Strength and support
release still require physical testing.

## Change and verify a recipe

Follow the [hardware workflow](../../README.md) for authority and retention.
The [manifest](manifest.json) selects the current projects and plate metadata;
[recipe locks](../recipes/projects.json) bind their exact bytes and instances.

1. Record the accepted CAD/recipe baseline and affected stable instances. Copy
   the complete project into a new ignored run with
   `python3 hardware/tools/printing/projects.py prepare --output hardware/.work/printing/NEW_RUN`.
2. Use the [candidate-only mesh helper](../recipes/README.md#replace-a-source-mesh)
   with independently reviewed source frames, or replace affected normal meshes
   in Bambu Studio. Preserve unrelated
   orientations, transforms, modifiers, blockers, inherited settings and object
   overrides. Reconcile persistent instance IDs if Bambu renumbers objects;
   labels alone cannot identify repeated instances.
3. Re-slice every affected complete plate. Review fit-critical cavities,
   supports, correct source frames, bed bounds and unchanged instances. Record
   tool/version, machine/nozzle/plate/material, process and coordinate offsets.
   Estimates are predictions, not measured outcomes. Changed geometry, material
   or machine invalidates previous toolpaths.
4. Update metadata/evidence and run
   `python3 hardware/tools/printing/projects.py check` and `make hardware-check`.
   Byte and structure checks do not replace support/toolpath review. Run
   `make check` before a completed implementation handoff.
5. Send the affected guide owner one handoff with quantities, estimates,
   settings, previews and limits. The guide derives project downloads, ZIPs and
   plate thumbnails from these maintained inputs; do not create competing copies.

For publication add `--release`; all independent source reviews and a selected
delivery must be resolved. The [semantic review contract](../recipes/README.md)
describes explicit equivalence evidence. Never clear a pending review simply by
updating hashes. Actual dispatch is separately authorized. Keep its results, printer queues and
stock records in ignored local `hardware/printing/operations/`; they are not
required public build inputs.

## Affected plates and retained process

| Plate | Recipe and change | Whole-plate estimate |
|---|---|---|
| W1 — white, plate 1 | R33 carrier/front upright; retained head/audio parts and blockers | 3h 28m 30s, 64.67g |
| K1 — black, plate 2 | R28 shell roof-down; 0.20 mm layers, 4 walls, 25% gyroid, 5mm outer brim / 0.12mm gap; normal/snug supports, 0.20 mm Z / 0.40mm XY; PLA 220°C nozzle / 60°C textured PEI | 12h 14m 24s, 289.52g |
| W2 — white, plate 3 | R33 lower/upper/middle LED brackets; rear upright and backpack retained | 4h 7m 44s, 60.76g |
| C2 — copper, plate 7 | R29 canisters upright; silk PLA 220°C / 55°C, 7.5 mm³/s; all other copper parts/settings retained | 3h 44m 26s, 48.63g |

Use the project and object-settings.csv for each object's overrides. K1 flow
calibration stays OFF because the layout intersects the calibration region at
Y12. The generic PLA bed-temperature warning remains. Confirm the X1 Carbon,
0.4mm nozzle, textured plate and selected material before printing.

The selected fingers-up/peg-down hands, side-down arm cores, front-down goggles,
collar inner-and-outer 8mm brims, P35 pin blockers, unsupported upright P10 and
antenna thread protection remain. Copper silk settings, including the C2
220°C nozzle / 55°C bed and 7.5mm³/s flow limit, are preserved. K1 and B2 plate estimates are inherited. The optional PETG ball uses the same
selected A05 mesh as the PLA project, with its own retained PETG process and a
fresh slice estimate of 22 m 25 s / 1.36 g.

## Support removal and assembly checks

K1 has four switch, six front and four rear blockers, plus one narrow
full-height blocker protecting both power nut slots and their screw bores.
Sampled paths show clear board/cover nut insertion regions. The FB24 tie slits
are intentionally closed. Small accessible front entry-edge support remains
above one lower seat; trim it before inserting the nut. Do not gouge a bearing surface to force fit.
Small rear roof bridges and the new pockets still need a real print/cleanup check.

The unchanged front grille uses four M3×6 screws and ordinary M3 nuts, no washers;
the rear grille uses M3×12. Load the front nuts before the audio cradle. Rear, power and audio nuts use open
slots with glue retention. Validate actual nut fit,
glue pull-out and screw engagement. Four WAGOs attach to the mounting pads with tape. Tape grade/thickness, adhesion on printed faces, adhesive tie mounts
and the full audio restraint route need physical qualification. Slicing establishes
none of these outcomes.

## Files and evidence

manifest.json, object-settings.csv and planned-settings.json describe the selected
recipe. source-provenance.json retains inherited recipe origins; live-source-check.json
binds this update to the registry-selected CAD. checks/r33-lighting-validation.json records the current changed-source, W1/W2 and preservation review. Earlier checks/r29-mesh-consistency-* records prior source/frame and support review, reused only for unchanged scope. Earlier checks/r29-* retains prior W1/W2/C2 review and arm frame corrections; checks/r28-* retains the unchanged K1 review; checks/r27-* preserves prior nut-slot evidence; checks/r26-* preserves W1; checks/r25-* preserves W2, and checks/r24-* preserves the preceding
base/cradle review. Other checks files preserve explicitly historical R23 evidence
for inherited recipes; they are not new R29 results. PUBLISHED.json is a current
file inventory, not proof of deployment or user approval. Git preserves superseded
project versions; current/ keeps only the selected pair.

Save experimental edits under ignored hardware/.work/. Before adopting a saved
project, use `hardware.tools.printing.privacy.sanitize_project(source, output)`
and `check_project(output)` on a separate candidate. These remove only nonempty
DesignerUserId metadata; verify geometry/settings preservation independently.

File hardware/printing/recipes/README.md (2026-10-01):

# Editable recipe checks

`python3 hardware/tools/printing/projects.py check` validates immutable project
bytes and archive integrity, settings, component/modifier meshes and transforms,
plate membership, build printability and catalog demand. The manifest-selected
download filenames must select exactly the validated recipe roles. `--json` returns structured readiness;
`--release` additionally requires the selected delivery and no outstanding source
review. `prepare --output <new-directory>` copies the complete accepted projects
and a baseline receipt. These commands never slice, dispatch or establish physical
qualification. Basic checks use Python's standard library and no installed Bambu
profiles.

`projects.json` binds the exact projects and `semantic-contract.json`. The whole-file
hash already protects every archive member; the historical member inventory is
not a second acceptance gate. Intentional edits require reviewing the changed
geometry/settings and updating the selected project identity. The latter
has persistent `recipe_instance_id` values assigned once, independently of Bambu
object IDs, labels and plates. Keep those stable identities through edits; update
the explicit numeric-object and plate mappings after review. Repeated labels are
valid. Duplicate stable IDs, reused numeric mappings and unassigned objects fail.
The mapping is a reviewed declaration, not an identity guessed from a label.

The source comparison uses the catalog-selected binary STL and a declared rigid
STL-to-raw-mesh frame, followed by the stored component and build transforms.
Every oriented triangle is compared, allowing vertex/triangle reordering and
welding of identical vertices. The 0.0001 mm coordinate tolerance covers the
recorded Bambu float roundtrip error below 0.000005 mm. Near-coincident ambiguous
matches require review. Different tessellation is unsupported; a topology mismatch
does not prove that the physical surfaces differ.

Each selected STL must also have nondegenerate triangles and closed,
consistently wound edges at its exact serialized coordinates. This check does
not round or tolerance-weld vertices: tiny open seams can make slicers fill
intended openings. It runs with `projects.py check`, including CI. It does not
prove absence of self-intersections or replace the affected full-plate slice
review.

The current contract verifies all 72 required/optional instance source meshes.
The projects reuse the selected downloadable STLs with independently reviewed
placement frames. No sampled surface-equivalence approvals are used. These checks
establish digital consistency; physical qualification remains separate.

## Replace a source mesh

Use the same accepted STL for the download and its print-project instances.
Do not make a second CAD export for the project or infer placement from its name.
Record the STL-to-project frame independently, including repeated instances.

The candidate-only helper consumes a hash-bound frame review:

```sh
python3 hardware/tools/printing/replace_meshes.py \
  --project baseline.3mf --review frame-review.json \
  --review-sha256 REVIEW_SHA256 --output NEW_DIRECTORY
```

The review declares `schema_version: 1`, `reviewer`, `method`, `project_sha256`,
a complete `instance_map` from stable instance IDs to Bambu object IDs, and
`replacements`. Each replacement supplies `recipe_instance_id`, a `source`
with `path` and `sha256`, and the reviewed 12-number `stl_to_mesh` matrix.
Source paths are absolute or relative to the review file.

The helper checks source identity and exact triangles while preserving unrelated
project content. It refuses unsupported mesh annotations instead of dropping
paint. Matching a supplied frame does not establish its intended orientation:
the independent frame review and candidate inspection establish that.
The output is a candidate, with affected preview caches invalidated. Follow the
[print procedure](../current/README.md#change-and-verify-a-recipe) to inspect and
re-slice affected plates before adopting it. The helper never updates current
files, changes Fusion, slices, or dispatches a print.

## Resolve an unsupported source comparison

After an independent reviewer establishes surface equivalence, add a JSON review
record and its frame evidence artifacts under `hardware/printing/recipes/reviews/`
in the same tracked change. Do not create an equivalence result until the actual
review is complete. Describe how the source frame maps to the raw normal component,
including component/build placement, and how different tessellations were compared.
The reviewer decides whether the method and stated limits justify equivalence.

The record must have this structure (placeholders below are documentation only):

```json
{
  "schema_version": 1,
  "reviewer": "Identified reviewer",
  "method": "Describe the actual independent surface/frame comparison and acceptance criteria",
  "result": "equivalent",
  "project_sha256": "<exact accepted whole-project SHA256>",
  "source_sha256": "<exact selected STL SHA256>",
  "recipe_instance_id": "<one persistent instance ID>",
  "frame_evidence": {
    "description": "Describe source and recipe frames and the verified mapping",
    "artifacts": [
      {
        "path": "hardware/printing/recipes/reviews/<frame-evidence-file>",
        "sha256": "<exact evidence SHA256>"
      }
    ]
  },
  "limitations": ["State method limits and any physical/support qualification excluded"]
}
```

For that one instance in `semantic-contract.json`, set `source_status` to
`reviewed_source_equivalence`, keep `stl_to_mesh` null, and add `source_review`
containing the record's repository-relative `path` and exact `sha256`. Preserve the
original `source_review_reason`. Update the contract hash in `projects.json` and
rebind selected delivery/current-input locks through the normal reviewed transaction.
Commit the record, every referenced artifact and the updated bindings together.
Offline validation works on an exported tracked tree without a Git index; it checks
location, content hashes and identities, while inclusion in the reviewed Git tree
is part of publication preparation.

The checker requires reviewer, method, an explicit `equivalent` result, exact
project/source/instance identities, frame evidence with at least one separately
hash-bound artifact, and declared limitations. Missing, failed, stale or edited
records/artifacts fail. Scratch, outside-directory and symlinked review
inputs fail. This disposition resolves only source geometry equivalence: immutable
project settings/modifiers/orientations, catalog demand, estimates, support review
and physical qualification keep their existing independent requirements. The current contract does not use surface-equivalence exceptions.

For a candidate roundtrip, provide separate JSON maps with `instances` and `plates`
objects, each mapping stable identity to its numeric Bambu ID string:

```sh
python3 hardware/tools/printing/semantics.py baseline.3mf candidate.3mf \
  --baseline-map baseline-map.json --candidate-map candidate-map.json
```

This strict comparison preserves global/plate/object/part settings, normal and
modifier triangle geometry, subtype, composed orientation and placement. Renumbered
objects/plates and changed labels are supported through the maps. Component
reordering, nested components, multiple build items for one object, intentional
setting or geometry changes require explicit review; no silently exempted parts
or positional object pairing is allowed.

Existing review evidence and inherited estimates retain independent `inputs`
bindings in the review receipt; updating a project/semantic lock alone makes the
old review stale. These bindings select the exact project
hashes and selected source hashes in the contract. An affected geometry or process
change invalidates those inputs and requires new bounded review and affected-plate
estimates. The preserved K1/C2 support audit sampled centerlines using the X1C Y+2
machine offset; it is neither a generic support checker nor proof of full bead
clearance. No slice determinism, completed print, fit or installed state is inferred.

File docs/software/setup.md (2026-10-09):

# Set up a Raspberry Pi

One application runs on the Pi, managed by `blooglyblob.service`. It uses
OpenAI over the internet; it is not an offline language model. The illustrated
build guide follows the same four stages below, before mounting the Pi.

## 1. Prepare the microSD card

Use a Raspberry Pi 3 Model A+ and Raspberry Pi OS Lite **64-bit**, based on
**Trixie with Python 3.13**. A Pi 3B+ has provided development evidence; final
physical qualification is still pending. Do not substitute a newer OS release
without checking support: the installer verifies the board, architecture, OS
and Python version.

On your computer, install Git, Make, Python 3.12 or newer, OpenSSH (`ssh`, `scp`)
and [Raspberry Pi Imager](https://www.raspberrypi.com/software/). Run terminal
commands in macOS/Linux, or inside [WSL on Windows](https://learn.microsoft.com/windows/wsl/install).
Use the same terminal environment throughout setup. Check that `python3`
selects your supported Python:

```sh
git --version
make --version
python3 --version
ssh -V
command -v scp
```

Use an existing SSH key from that environment. **Only if you need a new key**,
run the following and follow its prompts. Never overwrite an existing key;
answer no if prompted to replace one.

```sh
ssh-keygen -t ed25519
```

For the default key name, display the public key with:

```sh
cat ~/.ssh/id_ed25519.pub
```

If your existing key has another name, use its `.pub` path instead and ensure
its private key is selected by your SSH agent or an `IdentityFile` rule for this
Pi in the same terminal environment. Import only
this public-key line into Imager, never the private file without `.pub`. On
Windows, run Imager in Windows but paste the public key from WSL, or select that
WSL `.pub` file. A key suggested from the Windows account may not match the key
used by later WSL commands.

In Imager:

1. Choose Raspberry Pi 3, then Raspberry Pi OS Lite (64-bit). Confirm the
   description names Trixie.
2. Select the intended microSD card by name and capacity. Writing will erase
   that selected drive; stop if you cannot identify it confidently.
3. Choose a hostname and username, and keep both for SSH and `.env`. The examples
   below use `blooglyblob` and `builder`; replace them with your own choices.
   Set a private Pi password for any later sudo prompts.
4. Set Wi-Fi, country, time zone and keyboard layout in the controls provided by
   your Imager version. Enable SSH with public-key authentication and import the
   public key prepared above.
5. Review the device, OS, storage and settings. Write and verify the card, then
   eject it.

See Raspberry Pi's [installation instructions](https://www.raspberrypi.com/documentation/computers/getting-started.html)
for the Imager controls. No particular hostname or `pi` account is required.

## 2. Boot and connect

With power disconnected, insert the card. Rest the bare Pi on a clean,
nonconductive surface and connect a separate **5 V, 2.5 A micro-USB bench
supply** to its micro-USB power port. Allow a few minutes for first boot and
Wi-Fi. The computer must be able to reach the Pi on the network; the Pi also
needs internet access.

From your computer, substituting the identity you chose:

```sh
ssh builder@blooglyblob.local
```

If `.local` does not resolve, find the Pi in your router's device list and use
its IP address. A DHCP reservation can keep that address stable. On the first
connection, confirm you are contacting that Pi before accepting its host key.
Do not bypass a changed-host-key warning: verify a reimage or changed destination
before correcting `known_hosts`.

If SSH denies access, check the Imager username and that the imported public key
matches the key in your current terminal environment. A successful connection
shows a Pi shell prompt, for example `builder@blooglyblob:~ $`.

On the Pi, return to your computer terminal:

```sh
exit
```

Leave the Pi powered for configuration.

## 3. Configure BlooglyBlob

### Repository and target

On your computer, clone the repository and enter its folder. If you already have
a checkout, enter that folder instead of cloning inside it:

```sh
git clone https://github.com/demartinistudios/blooglyblob.git
cd blooglyblob
```

All subsequent Make commands run from this folder on your computer. Create the
settings files **only if absent**; these commands preserve existing files:

```sh
test -e .env || cp .env.example .env
test -e config/app.env || cp config/app.env.example config/app.env
```

Open `.env` in a text editor. Match the hostname/IP address and username that
worked for SSH; the example is:

```dotenv
PI_HOST=blooglyblob.local
PI_USER=builder
BLOOGLYBLOB_ENV_FILE=config/app.env
```

These are file contents, not shell commands. Do not add your Pi or Wi-Fi
password. An IP address or configured SSH alias also works. Explicit Make
invocation settings override exported environment values, which override the
saved root `.env`.

### OpenAI credentials

Create your own [OpenAI API key](https://platform.openai.com/api-keys) and enable
API billing. API usage is billed separately from a ChatGPT subscription. Your
account needs access to the configured models in `config/app.env.example`.
Application startup can make a billable greeting request; conversations and tool
requests also consume billable usage.

In your editor, put the key after `OPENAI_API_KEY=` in `config/app.env`. Keep the
other example settings. This file is ignored by Git; never commit it, share it
or include it in screenshots. Keep the path selected by `BLOOGLYBLOB_ENV_FILE`
in `.env`.

### USB audio selection

Connect the USB extension's male end to the Pi's USB-A socket, then connect the
loose audio module to its female socket. Keep the module in its case on the
bench. From the repository on your computer:

```sh
make pi-ssh
```

On the Pi:

```sh
cat /proc/asound/cards
```

Find the USB audio card and note the name after `USB-Audio -`. For example:

```text
1 [Device         ]: USB-Audio - USB PnP Audio Device
```

If no USB audio card appears, check the module and extension connections and
list the cards again. Note two names: the full name after `USB-Audio -` (for
`config/app.env` below) and the short card ID in brackets (`Device`). The volume
commands use the card ID, never the leading number, which can change after reboot.

Set the playback level on the Pi. For the specified Waveshare module and
speakers, inspect its `Speaker` control, then set both playback channels to 100%
(0 dB) and save the setting:

```sh
amixer -c Device sget Speaker
amixer -c Device sset Speaker playback 100%
sudo alsactl store Device
```

With the specified module, run them exactly as shown. If your brackets show a
different ID, type it in place of `Device`. Confirm both channels are
on and report `[100%]` and `[0.00dB]`. If the control is missing or has no dB
scale, stop here and inspect that module's controls with `alsamixer -c Device`.
At 100%, the module's 2.6 W per channel stays within the speakers' 3 W rating.
Recheck the level after reboot with `amixer -c Device sget Speaker`, and turn it
down if speech or music is too loud or distorted. If it is still too quiet at
100%, the module has a small volume screw inside its case (clockwise is louder;
see the [Waveshare FAQ](https://www.waveshare.com/wiki/USB_TO_AUDIO#FAQ)). Shut
down and disconnect power before opening the module. This is optional.

Leave the Pi shell:

```sh
exit
```

On your computer, edit `config/app.env` and set both audio names to the name
actually reported by your module. Remove the leading `#` if editing the
commented examples. For the example output above:

```dotenv
AUDIO_INPUT_DEVICE=USB PnP Audio Device
AUDIO_OUTPUT_DEVICE=USB PnP Audio Device
MIC_GAIN=1
```

The selected module provides both microphone and speaker audio. Names must
identify one input and one output unambiguously. A configured missing or
ambiguous device stops startup rather than silently choosing another device.
Start with `MIC_GAIN=1` (no extra software microphone amplification) for the new
module, then tune only after a voice test. It does not control speaker volume.
Provisioning preserves ALSA settings and does not retune volume.

## 4. Install, check and shut down

Use the bare Pi and loose USB audio module on the bench. **Keep all servo and
lighting circuits disconnected:** provisioning starts the application and there
is no software-only motion-disabled installation mode. Hardware tests and
[servo fitting](maintenance.md#commissioning-limits) happen later in assembly.

From the repository on your computer, check prerequisites:

```sh
make pi-check
```

The result must identify your intended Pi 3, `aarch64` or `arm64`, Python 3.13
and `VERSION_CODENAME=trixie`. If it fails, correct the SSH target or board/image
selection before continuing.

Install from your computer:

```sh
make pi-provision
```

Provisioning installs dependencies, the GPIO daemon and application service,
starts the application and enables it at boot. Sudo may request the Pi account's
password interactively; it is never stored in `.env`. There is no second
`pi-update` step needed for first installation. Existing remote configuration is
preserved on reruns.

Provisioning also moves the single Wi-Fi network set in Imager into native
NetworkManager storage, keeping its password and settings, so Raspberry Pi OS
does not regenerate it from Netplan at boot. No Wi-Fi file edits, network restart
or extra reboot are needed. The original files are kept in the private root-only
backup `/var/lib/blooglyblob-wifi-backup/`. Profiles that are already native are
left unchanged, and `pi-update` never changes networking. If provisioning finds
more than one Wi-Fi profile or another unfamiliar layout, it stops with a
message starting “Wi-Fi” before replacing the application. Do not delete
profiles to get past it: write the card again with one network set in Imager,
or move the profile to NetworkManager yourself and rerun provisioning. This keeps
the setting from being regenerated; it does not prevent every Wi-Fi fault.

### Reboot if provisioning requests it

If provisioning reports “Onboard audio is loaded and conflicts with GPIO18 LEDs”,
it has written an owned
module blacklist and needs a reboot. GPIO18 lighting cannot share PWM with
onboard analogue audio; see the driver's [PWM limitation](https://github.com/jgarff/rpi_ws281x#pwm).
No application files are replaced before this prerequisite passes.

On your computer:

```sh
make pi-ssh
```

On the Pi:

```sh
sudo reboot
```

SSH will disconnect. Wait for the Pi to rejoin Wi-Fi, then rerun
`make pi-provision` **on your computer**. If provisioning reports a different
error, fix that cause before continuing.

### Verify the service

On your computer:

```sh
make pi-status
```

Expect `active (running)`. Inspect the log next, especially if status is stopped
or failed:

```sh
make pi-logs
```

Press **Ctrl+C** to stop following logs and return to your computer prompt.
If the log reports missing credentials or an audio name, correct the installed
file; editing your computer's initial `config/app.env` no longer changes it.

For a configuration error, run `make pi-ssh` on your computer, then on the Pi:

```sh
sudoedit /etc/blooglyblob/app.env
```

Save and close the editor, type `exit`, then run on your computer:

```sh
make pi-restart
make pi-status
```

Do not mark setup complete until the application is running without configuration
errors. Do not run motion, microphone-recording or LED tests during bench setup.

### Shut down before mounting

On your computer:

```sh
make pi-ssh
```

On the Pi:

```sh
sudo poweroff
```

After SSH disconnects, wait for the green activity light to stop flashing.
Unplug the bench supply and USB audio lead before mounting the Pi and boards.

## Later assembly and operation

Follow the build guide's staged checks for the [supported LED chain](maintenance.md#supported-led-chain)
and [servo fitting](maintenance.md#commissioning-limits). With the head and arms
off the shafts, `make pi-servo-fit` holds the fit pose; seat the parts while it
holds, then type STOP, shut down, unplug and fasten them. Runtime uses fixed 1000–2000 µs limits at 50 Hz;
saved calibration does not override them. An existing robot needs refitting if
its horns were installed for different calibrated positions.

`make pi-check-audio` can inspect audio devices after installation. Keep physical
tests in their assembly stages. The button starts a conversation; there are no
wake-word models or keys. Follow the [release checklist](../release/checklist.md)
before claiming a new build or replacement audio arrangement is supported.

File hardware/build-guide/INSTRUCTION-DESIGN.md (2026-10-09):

# Designing the assembly instructions

Use this when authoring or reviewing the public guide. The builder should be able
to identify the part, see the movement or connection, perform it, and check the
result without reconstructing the design process. Keep research and review notes
out of the public steps.

## What the references contribute

Reviewed September 27, 2026. These are sources of guidance, not evidence that
BlooglyBlob has passed a physical build test.

- [iFixit: writing guides](https://www.ifixit.com/Info/Writing_Guides) recommends
  pictures and text that complement one another, consistent object orientation,
  direct language, and little background explanation. It cautions against vague
  part names and excessive annotations. Apply those lessons to CAD illustrations
  as well as photos.
- [iFixit: guide steps](https://www.ifixit.com/Help/Guide_Steps) connects image
  markers to the corresponding instructions. Our equivalent is a short label,
  visible destination and movement arrow, with a matching part name in the text.
- [Microsoft: step-by-step instructions](https://learn.microsoft.com/en-us/style-guide/procedures-instructions/writing-step-by-step-instructions)
  recommends concise action headings, numbered instructions, stating the location
  before the action, and avoiding introductions that repeat the heading. It
  permits closely related short actions to stay together.
- [LEGO Builder](https://www.lego.com/en-us/service/help-topics/article/lego-builder-app-3d-building-instructions)
  supports zooming and rotating models to inspect assembly. We retain enlargement
  for detailed inspection; the normal illustration must still explain the action.
  This guide does not implement interactive CAD rotation.
- [IKEA VIDGA instructions](https://www.ikea.com/us/en/assembly_instructions/vidga-corner-piece-single-track-included-ceiling-hardware-white__AA-2265275-2-100.pdf)
  provide a compact example of numbered assembly drawings with insertion,
  rotation and locking indications. We borrow that action-focused presentation,
  not a text-free rule: wiring polarity, screw sizes and tests still need words.
- [NN/g: instructional overlays](https://www.nngroup.com/articles/mobile-instructional-overlay/)
  describes the burden of dense tips, memorizing instructions away from their
  context, and text that refers to unmarked objects. This is interface research;
  applying its proximity and focus lessons to physical assembly is our inference.
- [ASD-STE100 Simplified Technical English](https://www.asd-europe.org/standards-specifications/simplified-technical-english/)
  limits procedural sentences to 20 words, with one instruction per sentence and
  an imperative verb. The [writing standard](#writing-standard) adopts these.
- [ANSI Z535.6](https://www.clarionsafety.com/safety-resources/machinery/understanding-ansi-z535-6-a-guide-to-safety-information-in-product-manuals-and-materials/)
  grades safety messages by signal word and requires each to state the hazard,
  consequence and avoidance beside the step it governs. See
  [Safety messages](#safety-messages).
- [Carroll's minimalism](https://www.instructionaldesign.org/theories/minimalism/)
  favors action-oriented text and support for recognizing and recovering from
  errors. This is the basis for result and recovery lines.
- [NN/g: how users read on the web](https://www.nngroup.com/articles/how-users-read-on-the-web/)
  finds that most readers scan, so the point goes first and extra words go.

## Rules for this guide

These rules cover pictures and page layout. The [writing standard](#writing-standard),
[safety messages](#safety-messages) and [names](#names) below cover the words.

1. **One operation per panel.** A heading states the action, not just the component
   name. A first screw and its identical repetitions may share a panel. A different
   tool, viewpoint or assembly state usually needs another panel.
2. **Show what changes.** Show the actual part and its mating feature. Use an
   arrow for insertion or motion, a leader for identification, and an inset for
   a hidden interface. Do not add a decorative arrow to a finished overview.
3. **Preserve orientation.** Keep front/left/right consistent across neighboring
   views. Say when to turn the assembly. Use a local locator only when needed;
   unrelated parts should not compete with the active joint.
4. **Make the fastening path visible.** Show the screw head side, washer location,
   receiving nut and access direction. Use accepted CAD for printed surfaces.
   Nominal hardware may clarify the joint but must match the verified size and
   axis. Show recognizable threads, recessed drives, nut bores and plausible
   material colors. Do not use plain yellow cylinders or blocks as hardware.
   Purchased-part recognition models must retain verified placement and dimensions;
   they do not establish fit or prescribe wire routing. Do not substitute boxes,
   a circuit schematic or a product picture for fastening instructions.
5. **Keep words beside their subject.** Put action text and necessary notes in the
   same panel as its image. At narrow widths, stack them immediately together.
   Avoid repeated full paragraphs inside the image and in the page. Use plain
   body text for necessary details; no quote-style borders, indented notes or
   repeated captions. Put required information directly in the action when possible.
6. **Write only what helps the next action.** Keep identity, quantity, dimensions,
   polarity, order, access constraints and the check for success. Remove internal
   coordinates, render commentary, revision stories and duplicated descriptions.
   Essential cautions belong before the action they affect, never in hidden help.
   State the general power rule once. Repeat it at power-state transitions
   and specific hazards, not throughout an uninterrupted unpowered assembly
   sequence.
7. **Prepare before mounting.** Test-route when length depends on fit, mark it,
   then solder and heat-shrink off the assembly. Check and cool the work before
   fitting it. Load captive nuts before access disappears; close covers last.
   Glue a nut only when it can fall out or turn before its screw is in, or when
   the design relies on adhesive to hold it. Otherwise load it in the same step
   as its part, right before the screws, and say how to hold it until the
   screw catches.
8. **Use compact framing, not tiny labels.** Show the local joint at a useful
   scale. Remove blank canvas and repeated figures before reducing size. Dense
   electrical diagrams need extra room; if their labels no longer read, split
   the diagram instead of relying on the enlarge button for essential facts.
9. **Use diagrams suited to the action.** Mechanical assembly needs geometry;
   electrical connections need named terminals and polarity; commands need
   readable code and the expected result. Do not invent a physical picture for
   a software-only action just to fill a template. Wiring actions should show both
   physical endpoints and a continuous wire between them. Distinguish an insulated
   wire crossing from a soldered branch, show the actual wire-entry face, and keep
   connector contact order separate from illustrative wire colors. Pair a complete
   connection view with a close-up when stripping, soldering or clamping needs one.
10. **Draw what the builder will see.** A picture shows the state its panel
    leaves, in the same pose and support the actions describe. Do not cram
    several stages into one drawing or use opposed arrows; when order matters,
    add small numbered callouts. Draw tools as tools: a meter probe has a tip
    and a handle, so it cannot be mistaken for a soldered wire. Draw heat-shrink
    one way, in one color, whatever tubing the builder uses: every joint, leg,
    resistor or loose wire end the actions cover is drawn under its sleeve in
    that panel's picture and in every later one. A sleeve over a resistor is
    drawn see-through, so the builder sees the resistor goes inside it. A sleeve waits on its lead
    only when the panel solders and a later panel shrinks it. Actions say
    "cover ... with heat-shrink", and say to slide it on before soldering when
    both wires already end in a plug or part. A render that
    contradicts its actions, such as one showing a retired stand, is recorded
    as a picture mismatch until it is re-rendered, and its caption says what it
    shows.
11. **Build steps only.** The guide has no service or repair steps; a builder
    who needs to open the robot reverses the build steps. After the last build
    chapter, the sidebar lists the reference pages under a plain chapter
    heading, Reference, without numbers and without a collapsible menu.
12. **Make detail optional, not the instruction.** Parts lists and references may
    expand on demand. The operation, required dimensions and safety information
    remain visible. Preserve keyboard navigation, readable contrast, image
    descriptions, zoom controls and printable output.

## Writing standard

This standard applies to every step title, action, result line, recovery line,
note, caption and safety message in the guide. It follows ASD-STE100 Simplified
Technical English for sentence length and imperative instructions, ANSI Z535.6
for safety messages, Carroll's minimalism for action-first text with error
recovery, and NN/g reading research for putting the point first.

### Who the guide is written for

Write for a hobbyist who can already solder, strip wire and run commands in a
terminal. Do not teach those skills. Define
only terms that belong to this project: its labels, assemblies, positions and
repeated actions. General terms such as AWG, JST, PLA, GPIO and heat-shrink need
no definition. Define each project term at its first use in the guide and in the
Build notes glossary, using the wording in [Names](#names).

### Limits

Automated checks enforce these limits as errors: `consistency.py check`,
`make guide-build` and `make check` fail on any violation.

| Rule | Limit |
| --- | --- |
| Words in one sentence | 20 or fewer |
| Words in one action (all its sentences) | 35 or fewer |
| Panels in one step | 6 or fewer |
| Actions in one panel | 1 to 3 |
| Instructions in one sentence | 1 |
| Part ID first used in a step | Plain name first, ID in parentheses |
| Banned terms | None of the terms in [Banned terms](#banned-terms) |
| Caption | Does not repeat its panel's action text |

Count words by splitting on spaces. A size or value with its unit counts as
one word when it has no space, such as `M3×6`, `W1/3` or `T1`. A step link
such as `{step:body-lights}` counts as one word. A command counts as one word.
The one-instruction check skips only code spans and software messages in curly
quotes (“…”). A straight " does not exempt text, because it is also an inch mark.

Simple mechanical steps should stay short: one to three panels. An action is one
to three short sentences; a panel holds one to three actions. A step that needs
more than six panels is two steps.

### Sentences

- **One instruction per sentence.** Do not join two instructions with "and",
  "then" or a semicolon. "Start all four screws by hand. Tighten them evenly." is
  two sentences, not one.
- **Verb first.** Start each instruction with an imperative verb: fit, insert,
  solder, label, check. A sentence may open with its location or condition
  instead, followed by the verb: "On the bench, solder…", "At W1, insert…",
  "If the output is short, extend…".
- **Location before action.** Say where before saying what: "At the front
  opening, hold the grille against the base." The reader finds the place, then
  acts.
- **Numbers and units.** Use numerals with units and a space: 11 mm, 5 V,
  1000 µF, 330 Ω. Write fasteners as `M3×6`. Spell out counts from one to nine
  before a fastener size ("four M3×6 screws"); use numerals for 10 and above.
- **Say the number when one is known.** "Strip 11 mm", not "strip a short
  length". Defer to a manufacturer's instructions only when the guide has no
  number, such as an epoxy's cure time. Name the source: "Let the epoxy cure for
  the time on its label."
- **No filler.** Remove "simply", "just", "easily", "carefully", "please",
  "make sure to" and "note that". Keep "gently" and "firmly" when they describe
  the force to use.

### Order within a step

1. **Title.** A verb phrase naming the operation: "Fit the front grille and rear
   vent", not "Vents".
2. **What you need.** Parts, fasteners and tools with quantities, visible at the
   top without expanding anything. Use the plain names from [Names](#names).
3. **Panels.** Each panel is one concrete operation, in the order the builder
   does it (rule 1 above). "Glue the eight board nuts" is one panel, with its
   seat, glue and wait actions inside it. Do not open a step with generic
   technique panels, such as "Seat each nut without glue" or "Glue each nut at
   its edge", ahead of the operations that use them. Teach a technique inside
   the first operation that needs it, then refer back to it. Each panel holds,
   in order: its title, any safety message, its actions, its result line and
   any recovery line. The picture sits beside or directly above them.
4. **Step check.** One line saying what the finished step looks like, or what a
   test shows. Write it as a statement, not an instruction.
5. **Note.** Only a link back or forward to another step ("You fitted these nuts
   in {step:board-cover-nuts}."). Never put an instruction, caution or fact the
   builder needs in a note.

### No pointless ceremony

Cut checks, confirmations, test-fits, reminders and result lines that have no
consequence at that point in the build. A "make sure the bottom cover closes"
check in the middle of the build is ceremony: nothing the builder can do then
depends on it. Say a real constraint once, in the step where it is acted on,
and link back to it rather than repeating it. Keep a check when it catches a
fault while it is still cheap to fix, such as a continuity test before a part
is mounted. Keep every required safety message.

### Physical sense

A rewrite must make physical sense at the bench, not only read well. For each
operation, check:

- which way the assembly lies, and which way each pocket, channel or opening
  faces in that position;
- whether a nut or part can fall out, slide or turn before it is fastened, and
  what holds it until then;
- what each hand is doing, and whether the builder can reach the part (never
  three hands);
- whether an earlier step leaves access for this one, and whether this step
  blocks a later one.

There is no service stand. When the robot must lie down, rest it on something
soft, such as folded towels. Say which way it lies and keep weight off the
head, arms and servos. In powered steps, keep moving parts clear so the robot
cannot tip.

Check against the step's pictures, `hardware/cad/CURRENT-NOTES.md` and the CAD
geometry. CAD is the source of truth for fastening details: screw direction,
nut pockets and which part holds which nut. Question inherited steps: an instruction is not correct because the
old text had it. When the sources do not settle a doubt, keep the current
wording, record the doubt in the work record and flag it to the owner. Do not
carry it over silently or guess a new procedure.

### Result and recovery lines

- **Result line.** After the actions it confirms, on its own line, as a
  statement the builder can see or measure: "The grille sits flat against the
  base." Do not hide the result inside an action sentence.
- **Recovery line.** Where a likely error is known, add "If you see X, do Y"
  directly after the action or result it applies to: "If a screw does not start
  by hand, remove it. Check that its nut is seated." Start recovery lines with
  "If". Do not
  invent a failure that has not been seen or reasoned from the design.

### Captions

Each kind of text has one job, the same in every picture:

- **Inside the picture: labels only.** Part names and IDs, wire colors and
  functions, pins, ports, sizes, quantities, connector size (JST-SM 2.5 mm or
  JST-SH 1.0 mm), a key for numbered marks or colors, and short pointers at one
  spot ("Cut here", "Slide in"). No title, no view line, no sentences, no
  instructions, results or disclaimers.
- **Under the picture: the caption.** Every step picture has one. It says what
  the picture shows and from where: the view direction, what is cut away or
  drawn apart, and what is highlighted. A picture used in several places has
  the same caption everywhere; two different pictures never share one, so the
  caption names what differs (LEFT or RIGHT cable, switch or LED pair). Name a part in full the first time a step
  mentions it, even in a caption.
- **In the actions: everything the builder does or checks.** A caption never
  repeats an action, gives an instruction, disclaims the drawing ("not to
  scale", "illustrative only", "does not show") or carries a fact the builder
  needs. Put needed facts in the action.

The writing check enforces the caption rules (`caption-missing`,
`caption-mismatch`, `caption-shared`, `caption-repeats-action`,
`caption-without-picture`), and
the drawing tests reject sentences inside generated wiring drawings.

## Safety messages

A safety message warns about a hazard in one action. Use one of three levels.
Do not use DANGER.

| Level | Use for | Examples in this build |
| --- | --- | --- |
| WARNING | Fire, electric shock or serious injury | A short circuit or a bypassed fuse; first power-up; mains supply; swallowed magnets |
| CAUTION | Minor or moderate injury | A reversed electrolytic capacitor; a servo moving with fingers near it |
| NOTICE | Damage to parts, with no injury | Cracking thin plastic; forcing a plug; tightening against a nut that is not seated |

Each message has three parts, in this order, in at most three sentences of 20
words or fewer:

1. **Hazard.** What is wrong or dangerous: "A wire from W1 to the light connector
   that skips F2 bypasses the light fuse."
2. **Consequence.** What happens if it is ignored: "A fault could then overheat
   the wires and cause burns or fire."
3. **Avoidance.** An instruction that prevents it: "Connect the light connector
   to W1 only through F2."

Placement and form:

- Put the message in the panel whose action it governs, before that action.
  A message that governs the whole step goes before the first panel.
- Store it as a `safety` entry on the panel or step, with a `level` of
  `warning`, `caution` or `notice` and its `text`. The guide shows the level
  label and styles it; do not type "WARNING" or add bold inside the text.
- Only safety entries carry safety wording. Do not write "warning", "caution",
  "be careful" or "danger" in actions, notes or captions.
- The general power rule and the general soldering, cutting and printing
  precautions live on the Safety and responsibility page. Repeat a power
  warning only at power-state changes and specific hazards (rule 6 above). Do
  not add a generic soldering caution to every soldering action: the audience
  already solders.
- Keep "Stop and unplug if…" instructions at power-up in the action list, as
  recovery lines, with a WARNING before the power-up action.

## Names

Each part, connector, assembly and repeated action has one name. Use it the same
way in actions, titles, captions, diagram labels, part cards and reference pages.

- **Plain name first.** On first use in a step, write the plain name with the ID
  in parentheses: "front microphone grille (FB41)". After that, either the name
  or the ID may be used in the same step.
- **Labels the builder writes follow the same rule.** W1–W4, F2, C1, C2,
  S1, S2, R1, R2 and J1 are written on the parts. Give the plain name at first
  use in a step, such as "input WAGO (W1/3)", then use the label alone. A port
  reference such as W1/3 counts as a use of W1.
- **Write a WAGO port as W1/3.** This means WAGO W1, port 3. Ports are numbered
  1 to 5 from the robot-right end of each WAGO.
- **Sides.** "Robot-left" and "robot-right" are the robot's own sides. Use them
  wherever a side matters. The servo labels LEFT and RIGHT mean robot-left and
  robot-right.
- **Wire, lead and cable.** A wire is one insulated conductor. A lead is a wire
  that comes attached to a component, such as a capacitor leg's wire or the
  fuse holder's loop, or a short purchased cable such as the Pi power lead.
  A cable is two or more wires that run together, usually to one plug.

### Connectors, labels and assemblies

| Thing | Name in text | Label written on it | Replaces |
| --- | --- | --- | --- |
| First JST-SM pair (E10), between the base and the body strand | body light connector; its two halves are the **base half** and the **body half** (the plug on the strand’s input end) | BODY LIGHT | BASE→BODY, H3, BODY, lighting lead |
| Wires from F2, C2 and S1 D5 (through R2) to the base half | base-half wires (+5 V, GND, DATA) | — | H3 +5 V, H3 return, H3 DATA |
| Second JST-SM pair (E10), between the body and the head | head light connector; its two halves are the **body half** and the **head half** | HEAD LIGHT | HEAD (as a connector), HEAD plug, HEAD latch |
| The strand’s three wires after light 5, with any extension, running up to the head light connector | head light cable | — | three-wire HEAD lighting cable, head power pair |
| Half of the cut JST-SH cable (E11), from the head half to the first eye’s IN | eye input lead | — | eye lead, 5755 lead |
| Other half of the cut JST-SH cable (E11), from the second eye’s OUT to the mouth pads | mouth lead | — | mouth leads, mouth power leads |
| Head half of the head light connector, the eye input lead, the eye cable and the mouth lead | head harness | — | mouth board and harness |
| Head shelf (P08) with the head horn adapter (P14) and its horn screwed on | head shelf assembly | — | — |
| Micro-USB lead (E22) from W1 and W3 to the Pi | Pi power lead | PI POWER | H2 |
| Servo cables | left arm servo cable, right arm servo cable, head servo cable | LEFT, RIGHT, HEAD | HEAD cable (for the servo) |
| Panel jack (E18) | power jack (J1); its contacts are the **center** and the **sleeve** | J1 | inlet, panel jack |
| WAGO W1 | input WAGO (W1) | W1 | — |
| WAGO W2 | servo power WAGO (W2) | W2 | — |
| WAGO W3 | ground WAGO (W3) | W3 | — |
| WAGO W4 | servo ground WAGO (W4) | W4 | — |
| F2 fuse and holder (E07) | light fuse (F2), T1 A | F2 | — |
| C1 (E08) | servo capacitor (C1) | C1 | — |
| C2 (E08) | light capacitor (C2) | C2 | — |
| S1, S2 (E15) | level shifter (S1), level shifter (S2) | S1, S2 | Pixel Shifter (except in the part card) |
| R1 (1 kΩ) | button LED resistor (R1) | — | — |
| R2 (330 Ω) | data resistor (R2) | — | — |
| One LED bead on the body strand (E05) | pebble | — | — |
| A place in the lighting data chain: body 0–5, eyes 6–7, mouth 8–15 | light 0 to light 15 | — | pixel (except in software output) |
| FB01 and everything mounted in it | base | — | enclosure, electronics enclosure |
| Central hole in the base's top wall, between the two frame screws, where the servo cables and body light connector enter | harness opening | — | central opening, central wire hole |

Retired names must not appear in guide text, captions, diagram labels, part
cards or generator labels once the rewrite is complete.

### Repeated actions

| Name | Meaning (glossary wording) | Replaces |
| --- | --- | --- |
| test-route | Run a wire along its final path without fixing or soldering it, to find its length. Mark it, then return to the bench. | dry-route |
| test-fit | Fit parts without glue or final tightening to check the fit, then remove them. | dry-fit |
| insert (a wire into a WAGO) | Strip 11 mm, push the bare wire fully into the port and close the lever. | land |
| connect (a wire to a board) | Fasten the wire in the named terminal, such as S1 D5, or push a jumper lead onto the named Pi pin. | land |
| fit position | The servo position set by `make pi-servo-fit`: head facing forward, arms hanging straight down. The robot also returns here when the application starts. | fit pose, rest pose |
| wire bundle | Two or more wires tied together along one path. Always say which wires. | bundle (alone) |
| seat | Push a plug or part fully home until it latches or sits flat. | — |

"Pull-check" and "dress" have no replacement term. Write the action plainly:
"Pull gently on the wire. It must stay in the port." and "Bend the USB cable so
the cover closes without pressing on it."

### Printed parts

Use these names in steps. Where the name differs from the current part card,
the part card changes to match.

| ID | Name in steps | Current part-card name |
| --- | --- | --- |
| A04 | antenna coil | same |
| A05 | antenna ball | same |
| AR01 | robot-left upper arm | same |
| AR02 | robot-left forearm | same |
| AR03 | robot-left relaxed hand | same |
| AR04 | robot-right upper arm | same |
| AR05 | robot-right forearm | same |
| AR06 | robot-right relaxed hand | same |
| AR07 | robot-left pointing hand (optional) | Pointing hand, robot-left (optional) |
| AR08 | robot-left shoulder cover | same |
| AR09 | robot-right shoulder cover | same |
| B01 | robot-left rear belt link | same |
| B02 | front belt link | same |
| B03 | belt buckle | same |
| B04 | robot-right rear belt link | same |
| B09 | belt pin | same |
| FB01 | base | Electronics enclosure |
| FB02 | bottom cover | same |
| FB03 | rear vent | same |
| FB19 | side speaker grille | same |
| FB20 | button insert | same |
| FB21 | power jack plate | Power inlet plate |
| FB24 | audio cradle | same |
| FB32 | audio cradle lid | same |
| FB41 | front microphone grille | same |
| GS01 | robot-left head strap | Robot-left gray head strap |
| GS02 | robot-right head strap | Robot-right gray head strap |
| GS03 | rear head strap | Rear gray head strap |
| GS11 | robot-right eye housing | Robot-right copper goggle housing |
| GS12 | robot-left eye housing | Robot-left copper goggle housing |
| GS20 | head shell | same |
| P01 | foam collar | Round foam collar |
| P02 | rear upright | same |
| P03 | shoulder-servo bracket | same |
| P04 | head-servo bracket | same |
| P06 | eye LED cassette | same |
| P08 | head shelf | Rotating head shelf |
| P09 | rear seam backing | same |
| P10 | rear seam cover | same |
| P11 | lower body-light bracket | same |
| P12 | middle body-light bracket | same |
| P14 | head horn adapter | same |
| P30 | mouth LED cassette | same |
| P31 | mouth light separator | same |
| P34 | curved backpack carrier | same |
| P35 | backpack shell | same |
| P36 | backpack tank | same |
| P37 | nozzle plug | same |
| P38 | robot-left backpack elbow | same |
| P39 | robot-right backpack elbow | same |
| P40 | backpack top band | same |
| P42 | upper body-light bracket | same |
| P43 | front upright | same |

### Banned terms

Automated checks flag these in guide text, captions and part cards. Replace
each with the name or wording given.

| Term | Use instead |
| --- | --- |
| land, landed, landing (a wire) | insert (into a WAGO port) or connect (to a terminal or pin) |
| dry-route, dry-routing | test-route |
| dry-fit, dry-fitting | test-fit |
| pull-check | "Pull gently on the wire. It must stay in the port." |
| fit pose, rest pose | fit position |
| dress | a plain instruction saying where the cable goes |
| enclosure | base |
| inlet, panel jack | power jack (J1) |
| central opening, central wire hole | harness opening |
| BASE→BODY, H3, BODY (as a connector) | body light connector, base half, body half |
| HEAD (as a connector), HEAD tails | head light connector, head light cable |
| H2 | Pi power lead |
| pigtail | the named lead: eye input lead, mouth lead |
| head power pair, input harness | retired with the daisy-chained lights: name the head light cable, the body half or the base-half wires |
| service stand, stand board, stand blocks | folded towels; say which way the robot lies |
| simply, just, easily, carefully, please, make sure, note that | delete |
| warning, caution, be careful, danger (outside a safety entry, except when quoting a message the software shows) | a safety entry |
| not to scale, illustrative, does not show (in a caption) | delete |

## Worked examples

These show the target form on two steps, written before the chapter rewrites.
The guide's own steps are now the reference for content. Each numbered line
here is one sentence; in the guide data, one to three sentences make one action.

### Example 1: Fit the front grille and rear vent (mechanical)

The current title, "Fit the front and rear vents", calls FB41 a vent. Its name
is front microphone grille, so the title changes.

The front nuts are loaded in this step, right before their screws, and are not
glued. Each front channel is open on the inside of the base, so a screw would
push a loose nut out. The nut only needs holding until its screw catches. After
that, the screw clamps the wall between the grille and the nut. A fingertip
holds it, so it needs no glue. The rear vent nuts are not glued either. Each is
placed right before its screw and held with a fingertip through the open
bottom until the screw catches.

**You need:** base (FB01) · front microphone grille (FB41) · rear vent (FB03) ·
four M3×6 screws · four M3×12 screws · eight M3 nuts · small drivers and hex
keys (T05)

**Panel 1: Find the two openings**

1. Place the base (FB01) upside down, with its open bottom facing up.
2. Find the front opening. The front microphone grille (FB41) fits here.
3. Find the rear opening. The rear vent (FB03) fits here.

*Caption:* View through the open bottom, with the front at the lower left.

**Panel 2: Load the four front grille nuts**

1. Find the four nut channels on the inside of the front wall, around the
   opening. Place an M3 nut flat against the wall in each channel.
2. Slide each nut toward the top of the base until it stops. Do not force it.
   Do not glue these nuts.

*Result:* Each nut rests at the end of its channel, over its screw hole.

*Caption:* Drawn upright: the arrow points toward the top of the base.

**Panel 3: Start the first grille screw**

> **NOTICE** The plastic behind the front nuts is thin. Too much force can
> crack it. Support the plastic behind the nuts while you work.

1. At the front opening, hold the grille against the outside of the base. Put
   one M3×6 screw through a grille hole. Use no washers.
2. With your other hand, press that hole's nut against the wall from inside.
   Turn the screw by hand until it catches.

*Caption:* Front wall cut away. Arrows show each screw's path.

**Panel 4: Fasten the front microphone grille**

1. Repeat for the other three holes, one screw at a time. Tighten all four
   screws evenly.

*Result:* The grille sits flat against the base.

*Recovery:* If a screw does not start by hand, remove it. Check that its nut is
seated.

**Panel 5: Hold a rear vent nut in its pocket**

1. Through the open bottom, place an M3 nut in one of the four pockets around
   the rear opening. Match its flats to the pocket. Hold it there with a
   fingertip. Do not glue it.

*Caption:* One rear vent pocket, before and after its nut is seated.

**Panel 6: Fit the rear vent**

1. With your other hand, hold the rear vent against the outside of the base.
   Put an M3×12 screw through the vent into that nut. Use no washer. Turn it by
   hand until it catches.
2. Repeat for the other three pockets, one nut at a time. Tighten all four
   screws evenly. Leave the bottom of the base open.

*Result:* The vent sits flat against the base.

*Caption:* Rear wall cut away.

**Check:** Both parts sit flat. Each nut stays seated and the plastic around it
is not cracked.

### Example 2: Wire the servo power and capacitor (wiring)

**You need:** capacitor (E08), 1000 µF, 10 V · 18 AWG wire (C05) ·
heat-shrink (C12) · solder, flux and wire labels (C14) · cable ties (C07) ·
adhesive tie squares (C17) · flush cutters (T01) · soldering iron (T02) · wire stripper (T04) ·
heat-shrink tool (T09)

**Panel 1: Cut and strip the servo feed**

1. Test-route a red 18 AWG wire from the input WAGO (W1/3) to the servo power
   WAGO (W2/1). Mark where it reaches without tension.
2. Cut the wire at the mark. Strip 11 mm from each end.

*Caption:* The servo feed wire, stripped at both ends.

**Panel 2: Connect the servo feed**

1. Insert one end into W1/3. Insert the other end into W2/1. Close both levers.
2. Keep W2/2 to W2/4 free for the three servos.

*Caption:* Wire-entry faces of W1 and W2.

**Panel 3: Prepare and connect the servo capacitor**

> **CAUTION** The servo capacitor (C1) is polarized. Connected backwards, it
> can overheat and vent when powered. Connect its striped negative leg to the
> ground WAGO (W3/4).

1. Label one 1000 µF, 10 V capacitor (E08) C1. The stripe marks its negative
   leg. On the bench, solder an 18 AWG wire to each leg. Mark the negative wire.
2. Cover each leg and its joint with its own heat-shrink. Lay C1 roughly where
   the layout detail shows. Cut each wire to reach its port.
3. Insert the positive wire into W2/5. Insert the negative wire into W3/4.
   Bend the wires gently at the rubber-seal end. Keep the vent end uncovered.

*Caption:* C1 with its sleeved wires, and the wire-entry faces of W2 and W3.

**Panel 4: Tie C1 down**

1. Choose a flat face beside C1. Prepare it as the square’s instructions say.
   Stick an adhesive tie square (C17) there.
2. Tie C1’s body to the square with a cable tie (C07). Keep the tie off the
   rubber-seal end and the vent end.
3. Tighten the tie only enough to stop sliding. Trim the tail. C1 is held by
   its tie, not by its wires.

*Caption:* Side view of a tie square holding a capacitor.

**Check:** One red 18 AWG wire joins W1/3 to W2/1. C1 polarity is correct.
Its two insulated wires are separate, and its body is tied down.

### How the examples meet the limits

| Limit | Example 1 | Example 2 |
| --- | --- | --- |
| Longest sentence (20 or fewer words) | 18 | 17 |
| Longest action (35 or fewer words) | 34 | 30 |
| Panels (6 or fewer) | 6 | 4 |
| IDs and labels named on first use | FB01, FB41, FB03 | E08, C1, W1, W2, W3 |
| Banned terms | none | none |
| Captions repeating an action | none | none |

## Builder checks and design validation

Write the assembly sequence for someone reproducing the specified design. Keep
checks of their work: correct parts and orientation, polarity/continuity,
insulated joints, connector seating, cable clearance, software startup and
expected light/sound/movement. Do not ask builders to qualify current budgets,
fuse margins, thermal performance or endurance, or buy instruments for those
tests. Maintain that engineering evidence in hardware records. Removing those
tasks from the guide is not evidence that design qualification has happened.

## Common failure patterns

| Failure | Why it fails | Fix |
| --- | --- | --- |
| Large completed-model render | Builder has to infer what changed | Show the joint and insertion path |
| Wrong related image | Familiar component disguises missing instruction | Match the pictured operation exactly |
| Many arrows or labels | No clear next action | Separate operations; keep only relevant pointers |
| Long image above a long paragraph | Constant scrolling separates explanation from target | Compact framing and adjacent copy |
| Text baked into huge image margins | Scaling makes either the page or the text unusable | Put prose in HTML; keep only diagram labels |
| Unannounced viewpoint change | Left/right and screw direction become ambiguous | Keep the viewpoint or explicitly show the turn |
| “Fit as shown” with no fastening detail | Omits the decision the builder needs | Show entry side, stack and receiving feature |
| Preparation after installation | Forces hot tools near plastic or needless disassembly | Prepare/check the loose subassembly first |
| Automatic “every image has an arrow” check | An arrow can still point to the wrong thing | Review the physical meaning against sources |

## Review at the bench and in the browser

For each changed panel, ask: which part, which face, which movement, which
fastener, and what tells the builder it is done? Verify that the drawing answers
those questions and that earlier steps leave access for this one. Use the
existing guide work record for specific findings and unresolved items.

Check desktop, tablet and 360 px phone layouts. Inspect normal-size labels as
well as enlarged images; inspect long electrical and software steps separately.
Check print output, no horizontal overflow, and no clipped commands or warnings.
Measure representative page heights before and after layout changes, but never
optimize scrolling at the expense of legibility. Automated checks cover routes,
assets and layout bounds; physical meaning still requires visual review and a
real build remains separate evidence.

For an illustration audit, inventory every authored image and generated plate
preview. Inspect contact sheets first, then enlarge suspect details. Trace every
cable to its connector or strain relief, every terminal tab to its component,
and every fastener along its receiving axis. Check projected heights as well as
plan coordinates: endpoints can share an x/y location yet look disconnected.
Check drawing order for objects hiding wires or filling through-holes. Compare
an action image with its text: a bare recess is not an installation illustration
of the magnet or horn that belongs there. Composite transparent images on the
actual page background before reporting missing or low-contrast geometry.
Record coverage, confirmed defects, corrections and uncertain details in the
existing guide record; a visual audit does not qualify physical fit.

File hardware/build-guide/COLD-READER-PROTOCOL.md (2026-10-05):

# Cold-reader test protocol

A cold read tests whether a new builder can follow the guide alone. One
participant builds from the guide while one observer watches and records. The
observer does not help. Each place the participant stops, re-reads, goes wrong
or asks a question is a finding against a step and a panel.

## Participant

Choose a hobbyist who matches the guide's audience:

- They can solder, strip wire and run commands in a terminal.
- They can take basic multimeter readings, such as continuity and DC voltage.
- They have not seen this robot, this guide or its source files.
- They have not helped anyone build it.

A participant is cold only once for each chapter. After they read a chapter,
their later findings on it do not count as a cold read. Use a new participant
to test a chapter again.

## Before the session

1. Pick the chapters for the session. Start at the first chapter the
   participant has not done. Plan to stop at a chapter end.
2. Record the guide revision under test: the Git commit, or the date of the
   published site.
3. Build and open the guide. Use the preview in the [authoring guide](README.md)
   or the published site.
4. Open the guide in a fresh browser profile or a private window, so no saved
   progress or parts ticks show.
5. Lay out the parts, supplies and tools that the chosen chapters list. Put
   them in their bags and boxes, not sorted by step.
6. Supply printed parts from earlier prints when the session is not about
   printing. The prints take about 39 hours, so start them well before.
7. For the Pi software chapter, provide a network and a computer with a
   terminal. Provide an OpenAI API key on a card if the participant has none.
   Revoke that key after the session.
8. Check the bench: ventilation for soldering, a fire-safe iron stand, eye
   protection and a first-aid kit.
9. Copy the [findings template](#findings-template) into a new file for this
   session. Use one file per session.
10. Get the participant's consent for notes and any photos. Do not record
    their name in the findings file; use a code such as P1.

The observer needs:

- This protocol and the findings file.
- A clock or timer.
- The guide open on a second screen, so they can see the step and panel the
  participant is on.
- A phone camera, used only with consent, to photograph wrong actions.

## Start the session

Read this to the participant:

> Build the robot from this guide as if you were alone at home. I will watch
> and take notes. I will not answer questions or explain anything, because I
> am testing the guide, not you. If you would normally search the web or open
> a datasheet, do so. When you pause, please say out loud what you are looking
> for. I will stop you only if something is unsafe.

Then start the clock and say nothing more.

## Observe in silence

- Do not help, explain, point or nod. Do not react to a wrong action.
- If the participant asks a question, reply: "What would you do if I were not
  here?" Record the question.
- If the participant is stuck for 10 minutes, ask whether they want to stop
  the step. If they do, give the smallest hint that lets them continue. Record
  it as an assist. That step no longer counts as a cold read.
- Let wrong actions happen. Record them and let the participant find them. A
  wrong action that the guide lets through is the most useful finding.

### When to intervene

Intervene only to prevent injury, fire or damage to a part that would end the
session. Say "Stop, please," and explain only the hazard. Examples:

- A hot iron or a blade near a hand, hair or cable insulation.
- Power about to be applied with bare conductors touching, or with reversed
  polarity at a supply, fuse, capacitor or board.
- Fingers near a moving servo or arm during a powered step.
- Solvent or epoxy use without ventilation.

Record each intervention as a safety stop, with what the participant was about
to do. Then let them continue from where they stopped.

## Chapters in order

Run the chapters in the guide's order. Do not skip ahead or reorder them, even
between sessions.

1. Prepare
2. Print
3. Base hardware
4. Pi software
5. Base boards and controls
6. Base wiring
7. Light test
8. Frame and servos
9. Head
10. Body
11. Arms
12. Backpack and belt
13. Final wiring
14. First power-up
15. Head and arm mounting
16. Close up and test

Test the Service steps in a separate session, on a finished robot. Start the
participant at "Before you start" in the first session. Start each later
session at the first step not yet done.

## What to record

Record each event against its step and panel:

- **Step:** the step number on the page and the step ID in the address bar,
  after `#step-`. Example: `27 servo-power-capacitor`. Service steps have no
  number; use their ID.
- **Panel:** the number at the top left of the panel. For the parts list at
  the top of a step, write `top`. For the safety box, the step note or the
  "Ready to continue" box, write `safety`, `note` or `check`.

Record these event types:

| Type | Record it when the participant |
| --- | --- |
| Hesitation | Stops for 30 seconds or more before acting. |
| Re-read | Scrolls back or reads a panel, caption or picture again. |
| Wrong action | Does something other than what the step intends, even if they later fix it. |
| Question | Asks something aloud, or says they are unsure. |
| Lookup | Leaves the step to find something: parts page, reference page, datasheet or web search. |
| Assist | Receives a hint from the observer. |
| Safety stop | Is stopped by the observer. |

Write what you saw, not why you think it happened. Quote the participant's
words where you can. Note the time of each event. Also record the start and end
time of each chapter, and any breaks for curing or printing.

## Findings template

Copy this section into a new file for each session. Name the file after the
date and participant code, for example `2026-10-04-cold-read-P1.md`. Keep
filled-in files with your private build notes, not in the repository.

```markdown
# Cold read: <date>, participant <code>

- Session type: cold read | owner bench walk-through
- Guide revision: <commit or published date>
- Observer: <name>
- Participant profile check: solders yes/no; terminal yes/no; meter yes/no;
  has not seen the robot yes/no
- Chapters covered: <first chapter> to <last chapter>
- Device and screen: <for example, laptop 14 in, phone 360 px>
- Start and end: <times>; breaks: <times and reason>

## Events

| # | Time | Step (number and ID) | Panel | Type | What happened | Participant's words | Severity |
| --- | --- | --- | --- | --- | --- | --- | --- |
| 1 | | | | | | | |

Severity: 1 = safety stop, or a part damaged or scrapped; 2 = wrong action
found later, or an assist; 3 = hesitation, re-read, lookup or wrong action
fixed at once; 4 = question or comment with no effect on the build.

## Triage (after the session)

| # | Cause in the guide | Proposed change | Review surface | Decision |
| --- | --- | --- | --- | --- |
| 1 | | | | fix / no change / bench check |

## Summary

- Chapters finished without an assist: <list>
- Severity 1 and 2 events: <count>
- Steps with three or more events: <list>
```

## From findings to guide changes

Findings change the guide only through the normal review process. Do not edit
the guide during a session.

1. Triage every event in the session's findings file. Decide: fix, no change,
   or bench check. A finding can point to a fact that needs a physical check,
   such as a cable length.
2. Make each fix by the [instruction design guidance](INSTRUCTION-DESIGN.md).
   Follow "Review an input or guide change" in the [authoring guide](README.md).
3. Set each affected surface in [review-status.json](review-status.json) to
   `pending`, with a one-line reason.
4. Run `make check`.
5. Review the changed surfaces again. Set them to `verified` with the revision,
   reviewer and evidence. Add concise public evidence to [REVIEW.md](REVIEW.md).
   Do not put participant names or identifying details in public files.

Test a fixed chapter again with a new participant before you count the fix as
confirmed.

## Owner bench walk-through

The owner, or anyone who knows the robot, can walk through the guide at the
bench with the same template. Set "Session type" to "owner bench
walk-through". This checks physical facts: fit, cable reach, tool access and
whether each procedure works. It is not a cold read. The owner knows the
intended result and fills gaps without noticing. Do not count a walk-through as
evidence that a new builder can follow the guide.

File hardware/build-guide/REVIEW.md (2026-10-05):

# Guide review scope

The guide selects R31 / Fusion cloud27 inputs. The
[review checklist](review-status.json) records digital review by surface, separate
from physical build qualification. Its broad review remains pending after the
build guide clarity overhaul; the focused updates below do not clear that review.

The retained R29 digital review covers the six changed part designs P08, P14, FB24,
FB32, P35 and P36:

- Shelf and adapter fastening axes match the accepted native bores. Screws enter
  from above and nuts sit beneath the shelf, assembled on the bench before the head.
- Cradle and lid illustrations show the asymmetric lid fasteners and enlarged USB
  opening. The connector illustration uses the measured loose connector envelope;
  endpoint locators do not assert a final mated position or cable bend.
- Tank assembly shows epoxy at the hidden ring contacts. The completed backpack
  stays removable with its four carrier screws. Installed quantities and both
  screw-key PDFs agree on five M3×8 screws and 60 M3 nuts.
- The affected part cards, assembly/service close-ups, base layouts and full-robot
  view were regenerated and visually reviewed. The base-cover view was regenerated
  and remained identical. Unchanged local interfaces and unrelated views were
  retained after dependency review.

The electrical instructions specify a direct 18 AWG servo feed from W1/3 to
W2/1, one F2 T1 A lighting fuse and the exact GST40A05-P1J supply. Service
instructions isolate servo power at W1/3 and restore it before final inspection.
The current native and STEP exports contain one lighting fuse reference.
The printed geometry, STLs, print projects and plate previews are unchanged.
Affected guide surfaces remain pending review; these instructions do not
establish physical qualification.

The [render source binding](../rendering/source-lock.json) records the reviewed
coordinates and accepted CAD identity. Native-bore regression tests check the
shelf and lid fastening axes. The guide consistency check covers allocations,
step references and writing constraints. Print projects and their plate previews
are maintained through the [print procedure](../printing/current/README.md).

Run `make check` to verify the current checkout. It checks data consistency and
browser behavior; it cannot determine whether every illustrated action is
physically correct. A visual review compares drawings with the selected CAD and
instructions, rather than treating a successful render as evidence of fit.

Physical assembly, tape and glue retention, actual connector clearance and cable
slack, acoustic behavior and complete powered operation remain unqualified.
All 72 print-source comparisons now pass the separate print recipe checks.
The STL downloads, plate previews and estimates are derived from those inputs.
P08/P14 now use closed native STL exports from the same R29 design. The W1
project and its derived downloads/preview were refreshed after full-plate slice
review. Native render geometry, assembly instructions and fastener locations
remain unchanged. Exact serialized edge checks supplement source matching;
they do not establish physical fit or rule out every slicer failure.
See [current hardware notes](../cad/CURRENT-NOTES.md) and the
[release checklist](../../../docs/release/checklist.md).

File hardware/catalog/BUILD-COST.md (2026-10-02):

# Build cost

Open the [build guide](../build-guide/README.md#build-and-preview) and choose
**Build cost**, or follow **Build cost & shopping list** on Parts & supplies.
The page compares three figures: **Materials used** per robot, and the
**Shopping total** with one black spool or with the guide colors. Its shopping
list shows order quantities, pack prices, line totals and purchase links. Part
cards use the same quotes.

[prices.json](prices.json) is the single source for dated US price quotes and
consumption allowances. The guide combines it with required part quantities and
the selected print plates’ estimated grams. Not included: tools, optional
prints, paint, tax, shipping, handling, import charges and OpenAI API use.

## How the figures are calculated

- **Materials used** charges each quote for the share of its pack one robot
  uses. Shared foam is split by cut area; filament is charged by plate weight.
- **Shopping total** rounds demand up to whole retail packs and spools.
  Shared foam is bought once; included accessories add no cost.
- **One black spool** combines all print mass into the catalog’s
  `single_color` PLA quote, so the antenna ball is opaque.
- **Guide colors** buys each filament color as its own spool.
- Each row is rounded to cents, and subtotals and totals add the rounded rows,
  so every figure on the page adds up.
- Both shopping totals assume the tools are owned and no supplies are on hand.
- Screws and nuts are priced individually; a generic assortment is not
  substituted for the specified sizes and head shapes.
- Wire, glue and tape quantities are planning allowances, not measured
  consumption.
- Printing in one color and painting is also an option; add the chosen finish.

## Updating prices

To update a price, edit its catalog quote, including the purchase URL and checked
date. `pack_price_usd` and `pack_quantity` use the same `unit` as consumption.
By default, consumption follows the part’s current required quantity. A
`used_quantity` sets a material allowance; `plate_color` selects the current
filament mass. `included_with` identifies an accessory already paid for with
another part. `purchase_group` combines demand sharing one physical pack; its
quotes must agree on price, quantity, unit and source. Group identity is explicit:
a shared product URL alone does not combine distinct filament colors. Multiple
quotes under one item describe its constituent supplies (solder, flux and labels)
or filament colors. `purchase_note` explains shared packs and buying choices in
the shopping list. `alternative_links` offers other sellers without changing the
quoted price; `shopping_notes` labels each category’s pricing source.

`make guide-build` recalculates all prices and fails on missing items, invalid
amounts, non-HTTPS links or unpriced filament colors; errors name the part.
There is no second maintained price table.

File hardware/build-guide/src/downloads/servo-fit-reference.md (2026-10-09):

# BlooglyBlob servo fit reference

This page backs up two build guide steps: "Hold the fit position" and "Attach the head shelf and arms". It lists the values the fit command uses and what to do if a part does not line up.

## The fit position

The fit position is the servo position set by `make pi-servo-fit`: head facing forward, arms hanging straight down. The application also moves the servos here when it starts.

| Servo | Pi GPIO (BCM) | Pi header pin | Signal wire | Fit pulse | Part position |
| --- | --- | --- | --- | --- | --- |
| Robot-left arm | 12 | 32 | S1 C5, labeled LEFT | 2000 µs | Hanging straight down |
| Robot-right arm | 13 | 33 | S2 D5, labeled RIGHT | 1000 µs | Hanging straight down |
| Head | 16 | 36 | S2 C5, labeled HEAD | 1500 µs | Facing forward |

Robot-left is the robot's own left: on your right when you face it.

The two arm pulses differ because the shoulder servos face opposite ways. The same arm position is at opposite ends of their travel.

## Hold the fit position

1. Start with the head shelf, head and both upper arms off the servo shafts. In the build, the robot stands on its feet, powered, after the light test. The head light cable runs up through a gap in the loose head shelf.
2. On your computer, in the `blooglyblob` folder, run:

   ```sh
   make pi-servo-fit
   ```

   It stops the robot application and holds all three servos at the fit position. Leave it waiting.

## Fit the parts while the servos hold

- **Head shelf:** turn the head shelf (P08) so its side with no nut pocket faces front. Set its horn on the head servo shaft, with the shelf front nearest straight ahead. Turn the shelf, not the shaft, to mesh them. Press it down.
- **Arms:** at the robot-left shoulder, on your right as you face the robot, set the robot-left upper arm (AR01) on its shaft, hanging nearest straight down. Turn the arm, not the shaft, to mesh them. Press it on. Seat the robot-right upper arm (AR04) the same way.
- If a horn does not slide on, lift it off, turn it one tooth and try again. Do not force it.

The spline has 21 teeth, about 17° apart. A part can sit up to half a tooth (about 8°) from the fit position. That is normal. Choose the nearest tooth. Do not force a horn or bend an arm to make up the difference.

## Release, shut down and fasten

1. At the waiting command, type `STOP` and press Enter. The output says the servo pulses stopped and the application stays stopped. If it says the servo output release is unconfirmed, unplug the supply from the wall at once.
2. Shut the Pi down:

   ```sh
   make pi-ssh
   sudo poweroff
   ```

3. Wait 30 seconds after SSH disconnects. Unplug the supply from the wall. Unplugging is the only power cutoff for the servos; there is no separate servo switch.
4. Hold the shelf still and drive the horn's own center screw. Do not use an M2 screw. Hold each upper arm still and drive its horn's center screw through the arm's outer face. Do not use a center screw to pull a horn onto the spline.

Unpowered shafts are not held in place. If a part turned while you fastened it, take it off and fit it again as above.

## After fitting

In the guide's "Check the first movement" step, the robot stands on its feet with the bottom cover off. When you plug the supply back in, the application starts by itself and moves each servo to the fit position. The head and arms may shift a little.

## Movement limits

The limits are built into the software. There is no calibration file to adjust, but every replacement servo still needs the fitting and first-movement checks above. All three outputs use 50 Hz (a 20 ms frame).

| Servo | Pulse range | What that means |
| --- | --- | --- |
| Robot-left arm | 1000–2000 µs | From hanging down (2000) up to about level in front |
| Robot-right arm | 1000–2000 µs | From hanging down (1000) up to about level in front |
| Head | 1000–2000 µs | About 45° each way from forward (1500) |

## If something is wrong

| What you see | What to do |
| --- | --- |
| `make pi-servo-fit` cannot reach the Pi | Check that the robot is plugged in and has had a minute to start, and that `make pi-check` works. |
| A shaft does not move, or buzzes and strains | Unplug the supply. Check that servo's three connections (+, − and signal) against the table above and the wiring step. |
| An arm or the head is a tooth off after fitting | Unplug, remove the center screw and lift the part off. Fit it again while the servos hold, as above. Do not turn the servo shaft by hand. |
| A part touches the body during the first-movement check | Unplug at once. Take that part off and fit it again while the servos hold, as above. |

A jammed servo can keep pushing and overheat. Unplug the supply immediately if an arm or the head strains.

BlooglyBlob: <https://github.com/demartinistudios/blooglyblob>

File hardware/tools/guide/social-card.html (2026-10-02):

 BlooglyBlob

Build guide

# Meet BlooglyBlob.

An open-source, 3D-printed talking robot you can build yourself.

A DeMartini Studios creation



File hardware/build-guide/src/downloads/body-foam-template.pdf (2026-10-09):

BlooglyBlob

# Body foam template

Print at 100% (actual size), landscape. Turn off Fit, Shrink and Scale to page. Check the 50 mm bar with a ruler before cutting. Cut from 4 mm white foam.

Shoulder hole, 14 mm | Shoulder hole, 14 mm

TOP EDGE · upper collar

FRONT CENTER

224.8 × 114.3 mm

The two short edges meet at the back with a 2 mm gap.

50 mm

Cut the outline a little long. Trim the ends after a test-fit between the collars. At the test-fit, mark each hole center over its shoulder servo shaft.

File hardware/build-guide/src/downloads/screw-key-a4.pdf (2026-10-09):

BlooglyBlob

# Actual-size screw key

Print at 100% (actual size). Turn off Fit, Shrink and Scale to page.

Check the 50 mm ruler and the 20 × 20 mm square with a real ruler before use. Measure from the middle of the printed lines. A screen is not a size reference.

0 | 50 mm

20 × 20 mm

check square

Lay each screw on its drawing with the underside of the head on the start line.
The length doesn’t include the head. Outlines show the largest head that fits:
M2 heads up to 3.8 mm across and 2 mm tall; M3 socket heads up to 5.5 mm across and 3 mm tall.

M2 × 6 · 15 used

M2 × 8 · 10 used

M2 × 10 · 8 used

M2 × 12 · 4 used

M3 × 6 · 7 used

M3 × 8 · 5 used

M3 × 10 · 2 used

M3 × 12 · 30 used

M3 × 14 · 2 used

M3 × 16 · 7 used

M3 × 18 · 2 used

M3 × 20 · 1 used

Three of the 10 M2 × 8 are button heads (drawn: 3.5 × 1.3 mm). They fix the head to its shelf, without washers.
M3 countersunk: 90° head, 6 mm across

Head top on the start line. The length includes the head.

M3 × 10 · 1 used

M3 × 14 · 2 used

Nuts, seen from above (ordinary hex nuts)

M2 nuts · 37 used M3 nuts · 59 used

Washers: inside and outside diameter

M2 metal: 4, 0.25 mm thick | M3: 8, 0.53 mm thick

M2 nuts are 4 mm across the flats and 1.6 mm thick.

Servo center screws · 3

These come with the servos and aren’t drawn here.

Keep each one with its servo horn.

Don’t use M2 screws in their place.

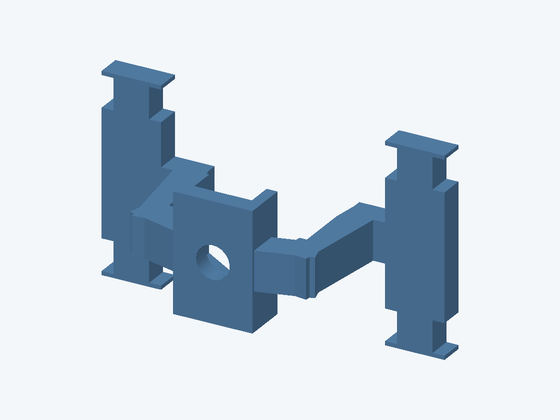
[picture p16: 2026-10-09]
hardware/build-guide/src/assets/part-P42.png

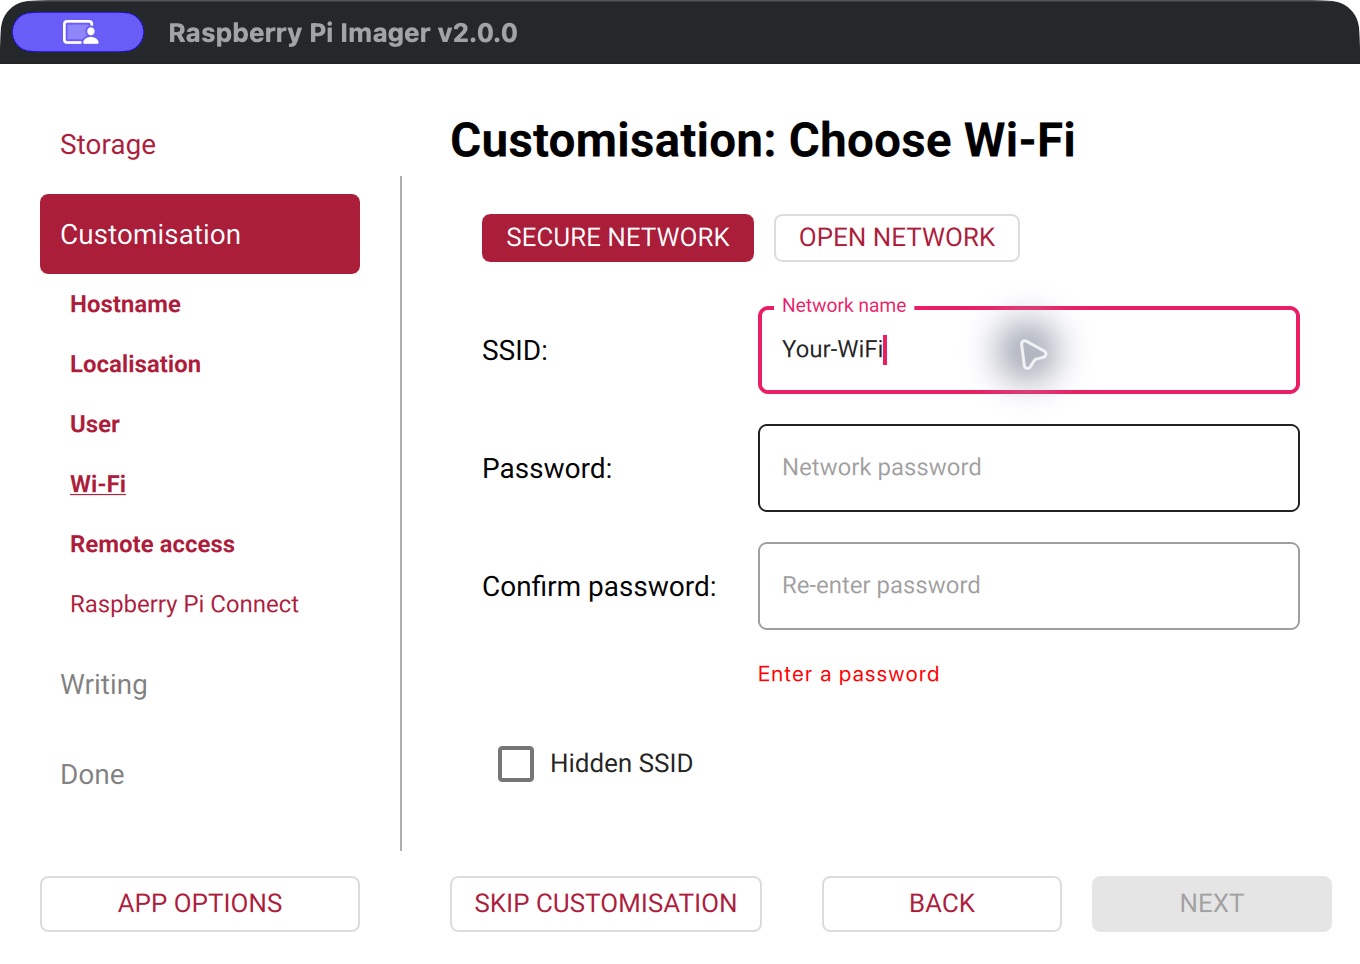
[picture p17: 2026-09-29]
hardware/build-guide/src/assets/setup/imager-wifi.jpg

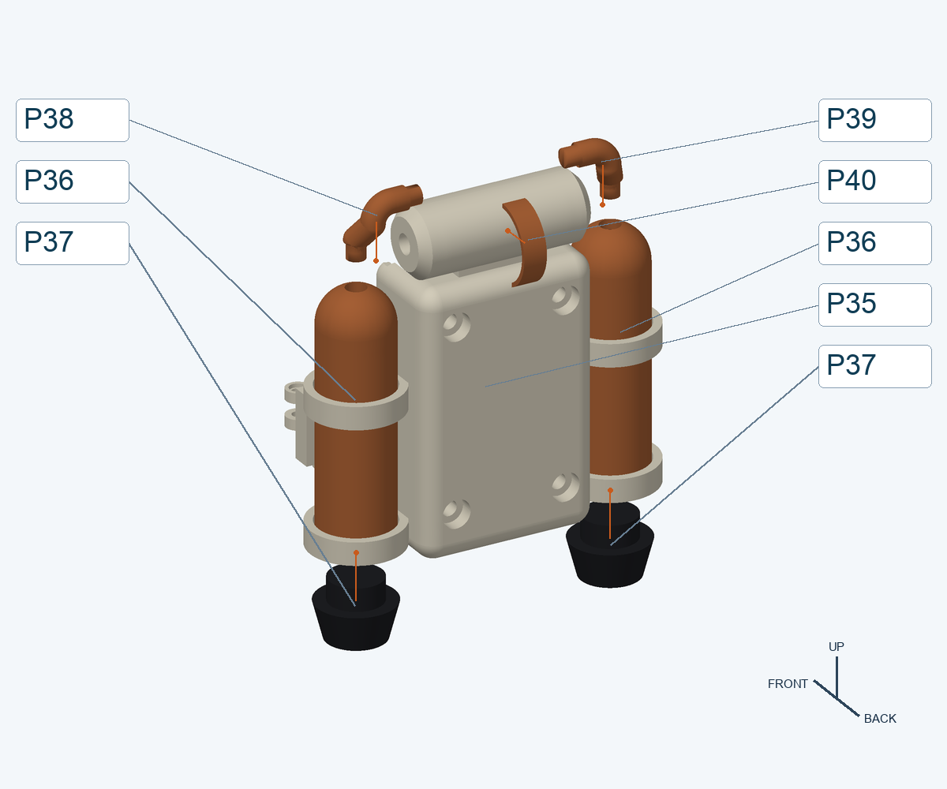
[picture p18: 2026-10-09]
hardware/build-guide/src/assets/r16/step-29.png

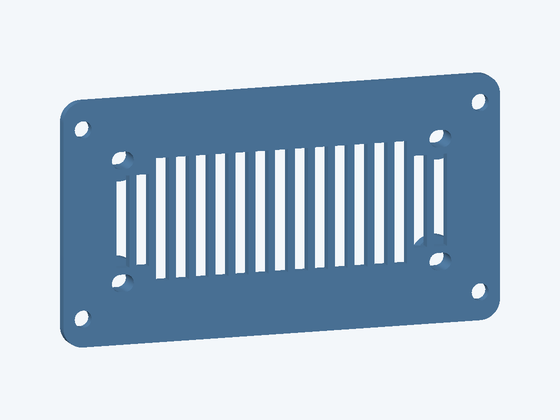
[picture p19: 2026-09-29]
hardware/build-guide/src/assets/r16/part-FB19.png

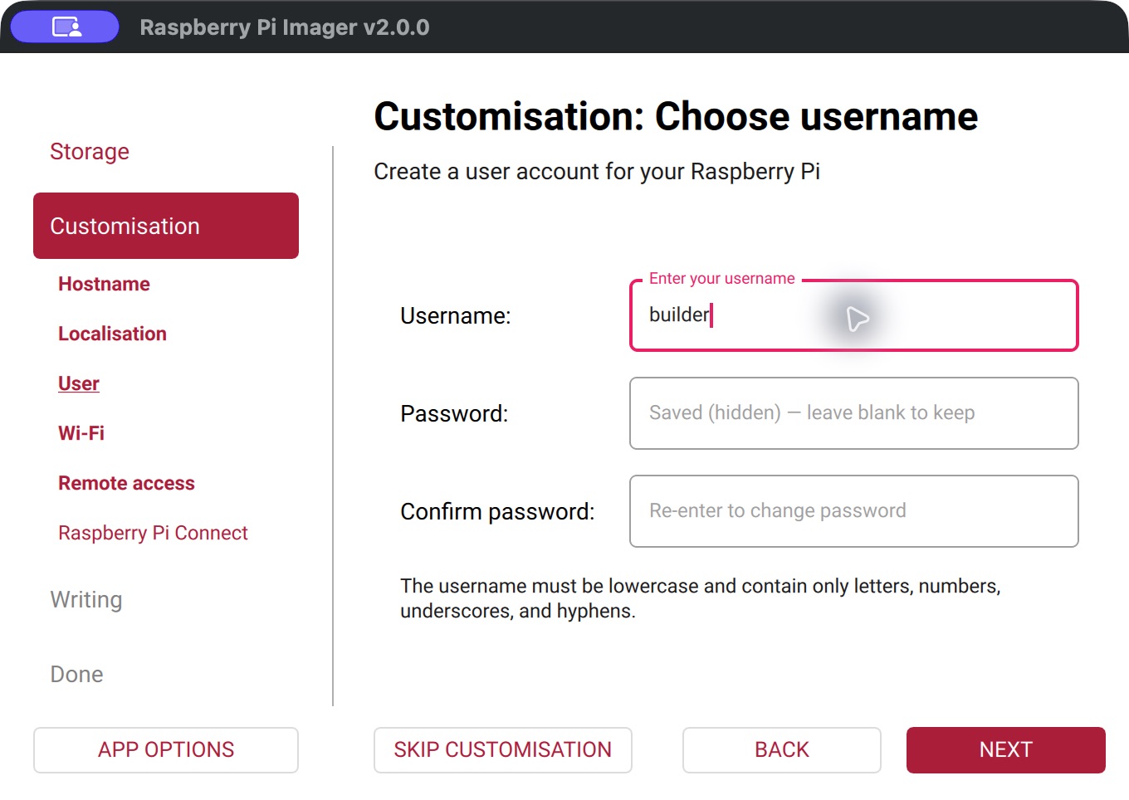
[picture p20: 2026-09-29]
hardware/build-guide/src/assets/setup/imager-user.jpg

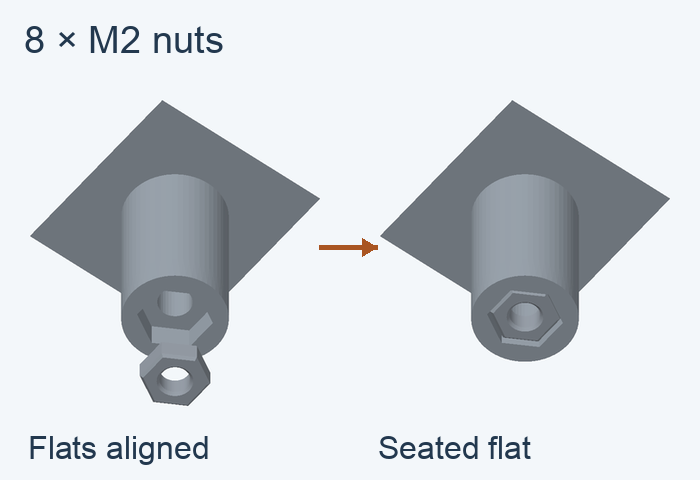
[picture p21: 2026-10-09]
hardware/build-guide/src/assets/community/base-board-nut-entry.png

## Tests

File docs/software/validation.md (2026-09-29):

# Software validation

Offline checks, installation checks and physical qualification establish different
things. Follow [setup](setup.md) and [maintenance](maintenance.md) for operating
procedures and [CONTRIBUTING.md](../../CONTRIBUTING.md) for contributor checks.
This page describes coverage and remaining limits, not a device-testing diary.

## Offline coverage

`make check` runs the repository's contributor checks, including formatting,
lint, types, software tests, hardware invariants and guide verification. See the
[CI workflow](../../.github/workflows/ci.yml) for supported Python versions and
installed-package checks. Run checks against the candidate being delivered;
historical test counts do not certify a later revision.

Tests replace native/cloud boundaries where needed. They do not move hardware,
record ambient audio or make paid API calls. Important coverage includes:

| Supported behavior | Current verification destination | Area |
| --- | --- | --- |
| Button activation, greeting, concurrent Live connect, microphone resumes after greeting | `test_openai_runtime.py`, `test_application.py::test_real_application_session_media_audio_chain` | Application and conversation |
| Context, corrections, inactivity/session ceilings, stale audio/results | `test_openai_runtime.py`, `test_openai_activities.py`, `test_openai_live.py` | Conversation and AI adapters |
| Scanner loops and ducks while microphone and speech continue | `test_audio_controller.py::test_scanner_and_stale_stop_preserve_capture_and_speech`, `test_background_sound.py`, `test_media_coordinator.py`, application chain above | Media and audio |
| Immediate mute, drain/flush, blocked drivers, cancellation and release failure | `test_audio_controller.py`, `test_capture_handoff.py`, `test_application.py` process-deadline/cleanup cases | Audio and application lifecycle |
| Sleep/dance announcements precede action; uncertain actions are not replayed | `test_openai_activities.py`, `test_openai_responses.py`, `test_openai_tool_executor.py` | Conversation and tool execution |
| Dance song, beats, completion and button return greeting | `test_hardware_tools.py::test_real_dance_uses_every_second_beat_and_clears_ambient_hold`, `test_hardware_controller.py`, `test_openai_activities.py` | Hardware local media and audio |
| Timer/doorbell preemption, chime, announcement, acknowledgement and outage dismissal | `test_openai_activities.py`, `test_openai_alert_ack.py`, `test_hardware_controller.py`, `test_runtime_resources.py` | Conversation, audio and integrations |
| Six animations, head direction/speed, ambient holds, LEDs and speech movement | `test_hardware_tools.py`, `test_hardware_presentation.py`, `test_hardware_controller.py` | Hardware controller and presentation |
| Ten logical tools, schemas, deduplication, bounded execution and context ownership | `test_tool_registry.py`, `test_openai_responses.py`, `test_openai_tool_executor.py` | AI tool bridge and tools |
| Content lookup, Roku, Ring setup, timers and overdue policy | `test_tool_handlers.py`, `test_roku_network_bounds.py`, `test_integration_configuration.py`, `test_runtime_resources.py` | Tools and configuration |
| USB selection, gain, resampling, coloration and resources | `test_audio_device_selection.py`, `test_audio_controller.py`, `test_pcm_resampler.py`, `test_openai_voice_effects.py`, `test_runtime_resources.py` | Audio and resource packages |
| Custom SSH host/user, provision/update repair, settings preservation, service controls and foreground restoration | `test_deployment.py`, `test_deploy_config.py`, `test_application_config.py`, `test_runtime_environment.py` | Installer and single service |
| Audio/microphone/servo/LED diagnostics and external calibration state | `test_deployment.py`, `test_runtime_environment.py`, `test_hardware_tools.py`; explicit physical qualification pending | Diagnostics and hardware modules |
| Beat analysis, model comparison, sound generators and license/assets | [Beat helper instructions](beat-analysis.md), `test_openai_model_evaluation.py`, deployment/resource and package checks | Optional scripts/resources |
| Privacy, settings precedence, literal env parsing and hardware-free imports | `test_log_privacy.py`, `test_application_config.py`, `test_runtime_environment.py`, `test_ai_mode_isolation.py`, `test_openai_orchestrator.py` | All owners and packaging |

## Servo fitting contract

Startup and `make pi-servo-fit` share immutable positions: left GPIO12 at 2000 µs,
right GPIO13 at 1000 µs and head GPIO16 at 1500 µs. Every axis uses 1000–2000 µs
at 50 Hz. Outputs open without a pulse; startup sets rest directly without a
sweep through center. The fit command requires the installation lock and a
confirmed service stop, holds outputs until STOP, releases without recentering
on STOP/EOF/interruption/failure, and leaves the application stopped.
Unconfirmed release reports status 73.

Saved legacy calibration files are preserved but ignored. Robots whose horns
were fitted at different positions must be refitted before operation. Regression
coverage checks fixed bounds, directions, cleanup, stop/lock refusal, ignored
calibration and agreement between instructions and configured outputs.
Physical pulse timing, loaded operation and assembly clearance require separate
qualification; nominal datasheet travel does not establish mechanical stop margin.

## Audio contract

Capture converts physical 48 kHz audio directly to the 24 kHz speech stream.
Offline coverage checks packet continuity, alias rejection, duration, converter
flushes, cancellation, gain preservation, generation fencing and playback drain.
See the [audio pipeline](audio-pipeline-cleanup.md) and
[runtime architecture](architecture.md). These tests do not prove acoustic echo,
USB/ALSA timing or clipping performance on the assembled device.

## Physical qualification

Full normal-application and acoustic qualification remain open. Maintainer tests
should exercise greeting, search, follow-up questions, interruption, button stops,
dance, alerts, timers, sleep, and API/network recovery with the current hardware.
Check voice consistency, speaker echo, tool actions and session closure without
duplicate or stale actions. Record exact software/dependency versions, board,
OS image, audio devices, gain settings and microphone/speaker placement privately.
Publish only the resulting useful limitations or verified supported behavior.

The existing proposed qualification protocol includes at least 30 button stops
across activities and a 60-minute mixed-activity run. Proposed measurement targets
are p95 button-to-audible-stop ≤250 ms and spoken interruption-to-old-speech-stop
≤500 ms, with at least 30 trials per scenario and no echo-triggered tool actions.
These are maintainer test targets, not achieved results or assembly steps imposed
on every builder. No latency or CPU/memory improvement is claimed.

A complete fresh Imager-to-Make installation, repeat provisioning, reboot,
update-failure/repair and representative use must be qualified for the reference
Pi and replacement audio. Software-only startup does not qualify speakers,
microphone placement, LED output, servo travel or loaded mechanics. Capture
clipping and missed follow-up behavior need evaluation in the complete assembly;
passing offline tests does not establish that these acoustic issues are resolved.

Physical diagnostics, motion and real API calls require explicit authorization.
For an authorized test, verify quiet human speech and speaker bleed before
accepting gain settings; change one variable at a time. Do not keep recordings
or transcript text in routine logs.

## Operational validation

After an authorized provision/update, use `make pi-status` and `make pi-logs` to
check readiness, restart counts, capture/playback errors and available memory
under representative use. Investigate failed media release, repeated restarts,
OOM or sustained swap dependence. Repair the reported cause and rerun the normal
procedure. Repository cleanup does not clear the
[release qualification checks](../release/checklist.md).

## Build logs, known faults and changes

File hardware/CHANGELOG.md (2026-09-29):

# Hardware changes and current guidance

The [current design](cad/CURRENT-DESIGN.md), [technical notes](cad/CURRENT-NOTES.md)
and [print procedure](printing/current/README.md) describe the selected hardware
and its limitations. Exact inputs and hashes live in the
[registry](cad/design-control/registry.json) and current input lock.

Keep public change descriptions concise: affected part IDs, resulting behavior,
required compatibility changes and known limitations. Detailed trial histories,
printer jobs and agent work records stay in ignored local folders. A metadata or
workflow change does not establish physical qualification.

The public print-project [privacy proof](printing/recipes/project-privacy.json)
records removal of personal account metadata without changing geometry or
settings. Source comparisons, guide review and physical qualification remain
separate checks; see the [release checklist](../docs/release/checklist.md).

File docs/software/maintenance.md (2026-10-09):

# Maintain the Pi software

`make pi-provision` establishes or repairs required system dependencies, the
Python environment, the application, and its service. It is safe to rerun and
preserves credentials, Wi-Fi, user settings, existing device files, and timer state. It
installs required packages without performing a blanket OS upgrade.

`make pi-update` updates application code and Python dependencies only. It
checks prerequisites and validates configuration before stopping the application.
If system dependencies need changes, run provisioning first. The application is
installed from one source snapshot. Only payload files are replaced; existing
custom state and media paths are preserved.

An update stops the application, replaces its code, restarts it, and waits for
systemd readiness. Required configuration, resources, audio-device selection and
button setup must succeed before the service reports ready. This does not start
a conversation or prove cloud access, acoustic quality or mechanical movement.
After readiness, background greeting preparation can make a billable Speech
request; starting the service is therefore not an offline-only operation.
If it fails after stopping, the robot may remain unavailable.
Inspect the reported step and logs, fix the cause, and rerun. There is **no
automatic rollback**, retained previous installation, or rollback command.
Manually installing an older version requires compatibility; it does not undo
system-package or data changes. Repeatable installation is not reversible
installation.

## Commands

| Command | Purpose |
| --- | --- |
| `make pi-check` | Read-only connection, remote identity, and OS/architecture check |
| `make pi-provision` | Complete first installation or dependency repair |
| `make pi-update` | Application update |
| `make pi-status` | Status of the application service |
| `make pi-logs` | Recent journal output |
| `make pi-start`, `pi-stop`, `pi-restart` | Control the application service |
| `make pi-ssh` | Open SSH to the configured target |
| `make pi-run` | Foreground application; restore its prior active service after exit, except ownership-uncertain status 73 |
| `make pi-servo-fit` | Hold all three assembly fit positions until STOP; release pulses and leave the application stopped |
| `make pi-check-audio` | Enumerate audio devices without opening streams |
| `make pi-test-audio`, `pi-test-mic` | Play a test tone, or beep, record five seconds of speech and play it back |
| `make pi-test-neopixels` | Exercise all 16 LEDs |

Only one provisioning/update/interactive diagnostic operation may own the
installation lock. Never remove another running operation's lock to force an
update. No command kills all Python processes on the machine.

### LED driver compatibility

Provisioning and updates automatically install a pinned source build of
`rpi-ws281x 5.0.0+bgb.1`. It applies the upstream
[Pi 3A+ revision 1.1 support](https://github.com/jgarff/rpi_ws281x/commit/09f4ef2b12b448ff1bd7d461b7b557139c8f2109)
to the hash-verified 5.0.0 source archive. Existing board entries, including
3A+ revision 1.0, remain unchanged. No board-specific builder command is needed.

The installer reuses that build on subsequent runs and checks board recognition
without opening GPIO before starting the application. Download, build or
recognition failure stops installation; fix the reported cause and rerun the
same command. The ordinary 5.0.0 constraint accepts this local build version.
Do not replace it with the unpatched PyPI package. Remove the backport after a
published Python release containing the correction has been qualified.

## Supported LED chain

The application supports one 16-pixel GRB NeoPixel **data** chain on GPIO18:

| Indices | Physical location | Normal application behavior |
| --- | --- | --- |
| 0–5 | Six body pebbles | Slow mood colors for the current state; asleep, a dim slow rainbow |
| 6–7 | Two separate eye pixels | Off while asleep; on and blinking while awake |
| 8–15 | Eight-pixel mouth | Off while asleep or silent; follows the speech level while talking and the music while dancing |

While the cloud service is unreachable, the body shows a slow, dim amber glow with the
eyes and mouth off. The robot stays inactive: button presses and alerts do not
start, and nothing is queued. It returns to normal idle when connectivity
recovers, without replaying an interrupted conversation; press the button again.

This data ordering does not change the power wiring. Retain the F2-protected
lighting supply defined by the hardware wiring guide; power and data run in one
chain through the body lights and eyes to the mouth. The brightness setting
remains 128/255.
This software profile does not establish electrical or thermal qualification.

`make pi-test-neopixels` first lights one pixel at a time in ascending order,
printing its index and zone, then runs the existing solid-color and animation
tests across all sixteen pixels. All pixels clear on exit. In ordinary use the
mouth lights only while the robot talks or dances. See commissioning
limits below before running diagnostics on a partially assembled build.

## Commissioning limits

Provisioning, updating, starting or rebooting starts the application and can move
servos. There is no motion-disabled installation mode. Follow the build guide's
staged power checks with the head and arms off their shafts before installing or
updating an uncommissioned mechanism.

`make pi-servo-fit` takes the installation lock, stops the application and confirms
its stopped state before opening any outputs. It holds all three servos at once:
robot-left GPIO12 at 2000 µs, robot-right GPIO13 at 1000 µs, and head GPIO16 at
1500 µs. All use 50 Hz. Type `STOP` and press Enter to stop pulses. EOF or an
interrupt also releases outputs without recentering. The application stays
stopped even if it was running beforehand. Shutdown failure reports status 73;
if that occurs, switch off the supply and resolve the fault.

Seat the head shelf and arms while the servos hold, then type `STOP`, shut down,
unplug and drive the center screws while supporting each part. Unpowered shafts
are not position-locked; if a part turns, repeat the fitting. Follow the
[servo fit reference](../../hardware/build-guide/src/downloads/servo-fit-reference.md)
for horn fitting and the guide's first-movement check. Every replacement servo
needs that fitting and clearance check.

Normal startup opens outputs without a pulse, then commands that same fit
position directly once, without a software sweep through center. Runtime movement
stays within **1000–2000 µs** on every axis. Fixed arm percentages map down to
forward raise in opposite pulse directions. Exact angles depend on the servo,
horn indexing and assembly. This operating window does not certify clearance;
wider travel needs separately observed qualification on the new assembly.

The old `pi-calibrate-servos` and `pi-test-servos` commands are retired.
`SERVO_CALIBRATION_FILE` and saved calibration JSON no longer control movement;
existing device files are preserved without being read or rewritten by the servo
controller. Before updating a previously calibrated robot, keep the head and
arms off their shafts and refit them for the fixed positions before operation.

Other diagnostics stop the application and restore it afterward if it was active
on entry. Run `make pi-stop` first when it must stay stopped. A LED or audio test
can therefore be followed by servo motion from application startup. Starting or
rebooting later can also initiate motion; STOP is not a latched power cutoff.

## Configuration and state

| Location | Contents |
| --- | --- |
| `/opt/blooglyblob/app` | Replaceable application and bundled resources |
| `/opt/blooglyblob/venv` | Application Python environment |
| `/etc/blooglyblob/app.env` | OpenAI key, audio settings and optional integration credentials |
| `/var/lib/blooglyblob/brain` | Persistent timers |
| `/var/lib/blooglyblob/device` | Preserved legacy device files; calibration is unused |

Explicit service environment values take precedence over the selected config
file. Files are parsed as data, without shell execution or implicit searches
through parent directories. Ordinary updates do not copy local credentials over
existing Pi configuration. Edit the remote configuration intentionally over SSH,
then run `make pi-restart`.

The application runs as root for the existing GPIO/LED drivers. Its internal AI,
audio and hardware modules share that process and privilege level.

Optional Ring/Roku setup helpers accept `BLOOGLYBLOB_ENV_FILE` and preserve other
settings. Their local default is `config/app.env`. Install
`requirements-integrations.txt` on the computer running the Ring helper. After
first installation, apply intended changes to the remote `app.env` deliberately;
rerunning provision or update does not overwrite it.

The Ring doorbell alert is experimental. Ring publishes no public API for it:
setup signs in with the community `ring-doorbell` library, and the application
then polls Ring's private app interface, which can change without notice. The
application does not refresh the saved login; if alerts stop, rerun
`make dev-setup-ring` and update the Pi's `RING_TOKEN`.

### First installation and repeated updates

Provisioning validates and privately installs the selected `app.env` when the Pi
does not already have one. Once installed, the remote file is authoritative:
updates and repeated provisioning validate it and preserve its exact contents.
Existing systemd drop-ins stay in place. The installer does not merge old
configuration files, reset saved state, or make recovery copies on each update.

The development Pi's conversion from two applications is complete. The installer
now supports fresh installations and updates of the single application. Existing
timer location remains in use and existing device files are preserved; their directory names
do not represent separate applications. Private recovery files from the completed
conversion may remain on that Pi, but are not part of installation or runtime.

### Failure and device ownership

Ordinary cloud errors with confirmed cleanup return the application to idle.
If a native worker or cloud transport cannot be confirmed closed, the application
mutes and exits with status 73. Systemd does not automatically restart that status.
Inspect `make pi-logs`, resolve the failure, then explicitly restart.

Interactive diagnostics hold the installation lock and stop the service first.
On interruption, the helper terminates and waits for the diagnostic process,
using a bounded kill-and-wait fallback. It restores the previous active service
only after confirming the process exited. Unconfirmed release leaves it stopped.
Foreground application exit status 73 also leaves it stopped, including when
that status is observed during interrupted cleanup. Process exit alone does not
override the requirement to inspect an ownership failure before restarting.

Streaming availability currently prefers US watch-provider results. When those
are absent, it uses the first region returned by TMDB. This is not a reliable
availability check for other countries; there is no region setting yet.

## Log privacy

Routine tool, timer, Roku, and Ring logs record operations, counts, outcomes,
retry timing, HTTP status codes, and error classes. They omit tool arguments,
timer labels, searches, content IDs, and Ring device names/IDs. Tool results and
saved timers still contain the information needed to perform the requested work.

Review logs before sharing them: other diagnostics can include paths, configured
device identifiers, network information, or third-party output. This cleanup
does not sanitize existing journal entries. Interactive
Roku discovery intentionally displays device names and addresses so you can
select the right device; keep that output private.

## Audio diagnostics and retention

The service emits one `Audio diagnostics:` JSON summary per ten-second reporting
window when measurements exist, plus remaining measurements at orderly shutdown.
Idle periods produce no diagnostic entries. Each window resets its counters and
maximums; audio can cross a window boundary, so compare several adjacent windows.
These summaries contain numeric counts, levels and timings, never microphone
recordings, transcript text, tool arguments or provider payloads. Existing activity
and generation entries place summaries in the conversation timeline.

- `capture_samples` counts 48 kHz microphone samples. `capture_overflows` counts
  PortAudio callbacks reporting lost input; it cannot recover or count the exact
  missing samples. `mic_raw` and `mic_processed` report sample count, RMS, peak
  and samples at the PCM clipping ceiling before and after resampling/gain.
- `handoff_*` counts 24 kHz PCM moving from the capture worker to the application.
  `input_not_listening_samples` identifies intentional rejection outside active
  listening (including the opening greeting). `input_accepted_samples` means the
  Live adapter accepted the call; `input_sent_samples` means the SDK append
  completed, which does **not** prove server recognition.
- `input_queue_frames` is the maximum queued 20 ms frames. `input_age_ms` measures
  enqueue-to-send-start delay; `input_send_ms` measures a completed SDK append.
  Capture and handoff queues have their own age/depth maxima. These are local
  queue measurements, not network round-trip times.
- `user_transcript_events` and `assistant_transcript_events` count fragments,
  not sentences or turns. `output_*` counts 24 kHz samples received, handed to the
  conversation, discarded by the adapter, or suppressed by conversation policy.
  Delivery to the conversation is not proof of speaker playback.
- `playback_written_samples` counts 48 kHz voice/mixed samples submitted
  successfully to the speaker; `background_written_samples` counts scanner-only
  output. Neither proves acoustic audibility. Playback submissions/discards are
  counted at 24 kHz before conversion. Queue cancellation and in-flight canceled
  SDK calls can leave delivery uncertain; discard counts describe known local
  disposal. Resampler buffers and failed native writes prevent an exact
  end-to-end sample balance.
- Session exit, speech gate, scanner and tool-result counters help distinguish
  idle timeout, cancellation and deliberately suppressed speech. `loop_lag_ms`
  measures lateness of the ten-second reporting timer, not every brief loop stall.

Use `make pi-logs` for recent service logs. For a bounded diagnostic export on the
Pi, run:

```sh
sudo journalctl --namespace=+blooglyblob -u blooglyblob --since '10 minutes ago' --no-pager
sudo journalctl --namespace=blooglyblob --disk-usage
```

Provisioning and updates install `/etc/systemd/journald@blooglyblob.conf`; the
service writes to that dedicated namespace. Journald rotates at 4 MiB per file,
uses a 64 MiB persistent budget, retains at most seven days of archived history,
and reserves 512 MiB free space. Size pressure can remove history sooner. The
volatile fallback budget is 8 MiB. Active files and journal overhead mean these
are journal budgets rather than byte-exact filesystem quotas. Normal messages
sync at most every 30 seconds, so abrupt power loss may lose the newest entries.

The policy covers this service's stdout/stderr as well as diagnostics. Other
services' retention is unchanged. Pre-upgrade entries remain in the default
journal under its existing policy; `+blooglyblob` includes those when reading.
Foreground `make pi-run` output goes to its terminal, not this retained journal.
There is no second application log file or custom rotation process.

## Local sound effects

The application opens bundled WAV files locally. Timer/doorbell alerts use
`sounds/alert_16k.wav`. Internet searches use `sounds/search_16k.wav`: a 30-second
electronic scanner that loops quietly until the search finishes or fails. The
audio controller prepares it during startup, then mixes it through the existing
conversation speaker writer. Voice energy lowers the scanner smoothly; its
background volume returns after a short speech pause. Speech and microphone
capture continue throughout. There is no minimum playback duration. Cancellation,
the button, generation flush and session failure stop it. Dance and alert
playback remain sequential.

Conversation and media modules own search activity and direct start/stop calls;
the audio controller owns mixing, looping and volume. Removing the background
effect confirms no more effect samples will be submitted, not that the speaker
has physically drained. Drain, flush and full release remain separate completion
boundaries. Background-only frames do not count toward speech playback progress.

Both recordings are synthesized without external samples and licensed under
[CC0](../../LICENSING.md). Their standard-library-only generators are MIT software:

```sh
python3 scripts/generate_alert_sound.py --output /tmp/alert-preview.wav
python3 scripts/generate_search_sound.py --output /tmp/search-preview.wav
```

Run these from the repository root. Each command overwrites its output file.
To replace a bundled sound, use its repository path as the output, update the
asset manifest and license hash, and run the deployment/package checks.
Dance playback remains local, using the song and its beat-timing file; see the
[beat analysis helper](beat-analysis.md) when preparing a replacement song.

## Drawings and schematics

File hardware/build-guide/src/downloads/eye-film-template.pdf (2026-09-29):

# Eye film template

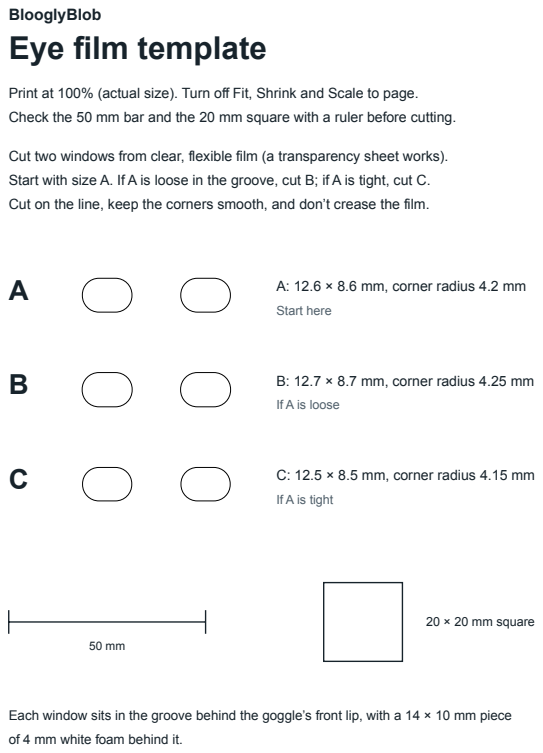
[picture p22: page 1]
BlooglyBlob; Start here; 20 × 20 mm square

Print at 100% (actual size). Turn off Fit, Shrink and Scale to page.
Check the 50 mm bar and the 20 mm square with a ruler before cutting.

Cut two windows from clear, flexible film (a transparency sheet works).
Start with size A. If A is loose in the groove, cut B; if A is tight, cut C.
Cut on the line, keep the corners smooth, and don’t crease the film.

A A: 12.6 × 8.6 mm, corner radius 4.2 mm

B B: 12.7 × 8.7 mm, corner radius 4.25 mm

If A is loose

C C: 12.5 × 8.5 mm, corner radius 4.15 mm

If A is tight

Each window sits in the groove behind the goggle’s front lip, with a 14 × 10 mm piece
of 4 mm white foam behind it.

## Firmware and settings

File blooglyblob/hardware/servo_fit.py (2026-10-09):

"""Hold the assembly fit pose; invoke through make pi-servo-fit."""

import argparse
import signal

# Shared exit contract with the application and stdlib-only installer. Avoid
# importing the full application and its audio/model dependencies for fitting.
OWNERSHIP_UNCERTAIN_EXIT = 73


def main(argv=None):
    argparse.ArgumentParser(description=__doc__).parse_args(argv)
    # Load configuration before importing any hardware settings. Importing this
    # module alone remains safe on a computer without GPIO drivers.
    from blooglyblob.config import load_runtime_environment

    load_runtime_environment()
    from blooglyblob.hardware import servo_controller
    from blooglyblob.hardware.local_media import HardwareReleaseError

    if not servo_controller.ON_PI:
        print("Servo fitting requires the Pi GPIO drivers; no simulation was run.")
        return 1

    def interrupted(signum, frame):
        raise KeyboardInterrupt

    handlers = {
        sig: signal.signal(sig, interrupted)
        for sig in (signal.SIGINT, signal.SIGTERM, signal.SIGHUP)
    }
    controller = None
    result = 0
    try:
        controller = servo_controller.ServoController()
        print(
            "Holding the fit pose. Seat the head shelf and arms now without turning the shafts."
        )
        while (
            input("Type STOP then Enter to release the servos: ").strip().upper()
            != "STOP"
        ):
            pass
    except (EOFError, KeyboardInterrupt):
        print("Servo fitting interrupted.")
        result = 1
    except HardwareReleaseError:
        result = OWNERSHIP_UNCERTAIN_EXIT
    except Exception:
        print("Servo fitting failed; inspect the outputs before continuing.")
        result = 1
    finally:
        for sig in handlers:
            signal.signal(sig, signal.SIG_IGN)
        try:
            if controller is not None:
                try:
                    controller.cleanup()
                except Exception:
                    result = OWNERSHIP_UNCERTAIN_EXIT
        finally:
            for sig, handler in handlers.items():
                signal.signal(sig, handler)
    if result == OWNERSHIP_UNCERTAIN_EXIT:
        print("Servo output release is unconfirmed. Switch off the supply.")
    elif result:
        print("Servo pulses stopped. The application stays stopped.")
    else:
        print(
            "Servo pulses stopped. The application stays stopped. "
            "Shut down and unplug, then drive the center screws."
        )
    return result


if __name__ == "__main__":
    raise SystemExit(main())

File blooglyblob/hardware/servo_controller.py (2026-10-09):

"""High-level servo controller for Blooglyblob.

Provides semantic control of servos using fixed positions:
- ArmServo: up(), down(), wave(), set_percent()
- HeadServo: look_left(), look_right(), center(), shake_no(), nod_yes()
- ServoController: Unified control of all servos with preset animations

All movements are smooth by default and respect the fixed operating window.
Fit parts with `make pi-servo-fit` before checking assembled clearance.
"""

from contextlib import contextmanager
import logging
import signal
import threading
import time
from typing import Optional

# Only import GPIO libraries when running on Pi
try:
    from gpiozero import Servo
    from gpiozero.pins.pigpio import PiGPIOFactory, PiGPIOPin
    ON_PI = True
except ImportError:
    ON_PI = False
    Servo = None
    PiGPIOPin = object

from blooglyblob.hardware.config import gpio_config
from blooglyblob.hardware.local_media import HardwareReleaseError
from blooglyblob.hardware.servo_config import (
    LEFT_ARM, RIGHT_ARM, HEAD, ServoProfile,
    MIN_PULSE_WIDTH, MAX_PULSE_WIDTH, FRAME_WIDTH,
)

# Default movement settings
DEFAULT_STEP = 0.02
DEFAULT_DELAY = 0.015  # 15ms between steps for smooth movement
logger = logging.getLogger(__name__)


class _ServoSignalPin(PiGPIOPin):
    """Release servo signals to pulled-down inputs instead of floating inputs."""

    def close(self):
        if self.factory.connection:
            self.frequency = None
            self.when_changed = None
            # Arm the pull-down while the output is still low. gpiozero's
            # default close floats the input, allowing stray servo pulses.
            self.factory.connection.set_pull_up_down(
                self._number, self.GPIO_PULL_UPS['down'])
            self.function = 'input'
            self.pull = 'down'


@contextmanager
def _protect_release():
    """Let main-thread teardown finish before restoring interrupt handlers."""
    handlers = {}
    try:
        if threading.current_thread() is threading.main_thread():
            for sig in (signal.SIGINT, signal.SIGTERM, signal.SIGHUP):
                handlers[sig] = signal.signal(sig, signal.SIG_IGN)
        yield
    finally:
        for sig, handler in handlers.items():
            signal.signal(sig, handler)


def _create_servo(pin: int) -> Optional["Servo"]:
    """Create a gpiozero Servo with pigpio backend."""
    if not ON_PI:
        return None

    factory = None
    try:
        factory = PiGPIOFactory()
        factory.pin_class = _ServoSignalPin
        return Servo(
            pin,
            initial_value=None,
            min_pulse_width=MIN_PULSE_WIDTH,
            max_pulse_width=MAX_PULSE_WIDTH,
            frame_width=FRAME_WIDTH,
            pin_factory=factory,
        )
    except BaseException as error:
        if factory is not None:
            try:
                with _protect_release():
                    factory.close()
            except Exception:
                raise HardwareReleaseError("Servo factory release failed") from None
        if not isinstance(error, Exception):
            raise
        print(f"Failed to create servo on GPIO {pin}")
        return None


class BaseServo:
    """Base class for servo control with smooth movement."""

    def __init__(self, pin: int, profile: ServoProfile, name: str):
        self.pin = pin
        self.profile = profile
        self.name = name
        self._servo = _create_servo(pin)
        if ON_PI and self._servo is None:
            raise RuntimeError(f"Servo output unavailable on GPIO {pin}")
        self._position = profile.rest

        # Don't move on individual servo init - ServoController.fit_pose() handles startup position

    @property
    def position(self) -> float:
        """Current position (-1.0 to 1.0)."""
        return self._position

    @position.setter
    def position(self, value: float):
        """Set position immediately (no smoothing)."""
        value = self.profile.clamp(value)
        changed = value != self._position
        self._position = value
        if self._servo:
            self._servo.value = value
        if changed:
            self._trace_head('target', value)

    def _trace_head(self, phase: str, target: float):
        """Record commanded targets, not measured shaft positions."""
        if self.pin == gpio_config.HEAD_PIN:
            logger.info('Head command phase=%s target=%.4f source=%s',
                        phase, target, threading.current_thread().name)

    def move_to(self, target: float, speed: float = 1.0):
        """Move smoothly to target position.

        Args:
            target: Target position (-1.0 to 1.0)
            speed: Movement speed multiplier (0.5 = half speed, 2.0 = double)
        """
        target = self.profile.clamp(target)
        self._trace_head('start', target)

        if self._servo is None:
            self._position = target
            self._trace_head('complete', target)
            return

        step = DEFAULT_STEP * speed
        delay = DEFAULT_DELAY / speed

        current = self._position
        direction = 1 if target > current else -1

        while abs(current - target) > step:
            current += step * direction
            self._servo.value = current
            time.sleep(delay)

        self._servo.value = target
        self._position = target
        self._trace_head('complete', target)

    def neutral(self, speed: float = 1.0):
        """Return to the fixed rest position."""
        self.move_to(self.profile.rest, speed)

    def detach(self):
        """Stop sending PWM signal (servo goes limp)."""
        if self._servo:
            self._servo.detach()

    def cleanup(self):
        """Close the servo and its owned pigpio connection, observing failures."""
        if self._servo:
            servo = self._servo
            errors = []
            for close in (servo.detach, servo.close, servo.pin_factory.close):
                try:
                    close()
                except Exception:
                    errors.append('close')
            if errors:
                raise HardwareReleaseError('Servo release failed')
            self._servo = None
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

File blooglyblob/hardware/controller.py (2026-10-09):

"""Direct hardware operations; importing this module never imports Pi drivers."""
import asyncio
from contextlib import ExitStack
from importlib.resources import as_file, files
import logging
import os
from pathlib import Path
import threading

from .lighting import LightingState
from .music_lights import load_lights
from .conversation_state import ConversationMode, ConversationState
from .local_media import HardwareReleaseError, LocalMedia, Worker

log = logging.getLogger(__name__)
ANIMATIONS = {name: name for name in ('wave_hello', 'celebrate', 'think', 'shrug', 'six_seven', 'attention')}
HEAD_SPEEDS = {'slow': .5, 'normal': 1., 'fast': 2.5}


def _servos():
    from .servo_controller import ServoController
    return ServoController()


def _leds(**kwargs):
    from .led_controller import LEDController
    return LEDController(**kwargs)


def _ambient(**kwargs):
    from .ambient_animator import AmbientAnimator
    return AmbientAnimator(**kwargs)


def _button():
    from gpiozero import Button
    from gpiozero.pins.pigpio import PiGPIOFactory
    from .config import gpio_config
    try:
        factory = PiGPIOFactory()
    except Exception:
        factory = None
    try:
        button = Button(gpio_config.BUTTON_PIN, pin_factory=factory, bounce_time=.02)
    except Exception:
        if factory:
            factory.close()
        raise
    # gpiozero does not own a caller-supplied pin factory.
    return button, factory


class HardwareController:
    """Loop-owned lifecycle, GPIO-safe mute, and independent presentation.

    Callbacks are synchronous loop callbacks: on_button(),
    on_dance_finished(activity_id), on_failure(activity_id, sanitized_reason).
    Activity authority remains with the caller; completions never change it.
    Optional factories use the native constructors' keyword arguments. The
    required button factory returns a button or (button, owned_pin_factory).
    """

    def __init__(self, audio, on_button=lambda: None, on_dance_finished=lambda _: None,
                 on_failure=lambda *_: None, *, media_dir=None,
                 servo_factory=_servos, led_factory=_leds, ambient_factory=_ambient,
                 button_factory=_button, operation_timeout=3.):
        self._loop = asyncio.get_running_loop()
        self.audio = audio
        self._on_button, self._on_dance, self._on_failure = on_button, on_dance_finished, on_failure
        self.presentation = ConversationState()
        self.lighting = LightingState(audio.presentation)
        self.music_lights = None
        self.lights_path = None
        self.animation_lock = threading.Lock()
        self.servos = self.leds = self.ambient = self.button = self._pin_factory = None
        self._servo_factory, self._led_factory = servo_factory, led_factory
        self._ambient_factory, self._button_factory = ambient_factory, button_factory
        self._media_dir = media_dir if media_dir is not None else os.getenv('BLOOGLYBLOB_MEDIA_DIR')
        self._resources = ExitStack()
        self.alert_path = self.dance_path = self.beats_path = self.search_path = None
        self._timeout = operation_timeout
        self.media = LocalMedia(audio, self, timeout=operation_timeout)
        self._prepared = self._closed = False
        self._prepare_task = None
        self._close_task = None
        self._native_workers: list[Worker] = []
        self._gestures: list[Worker] = []
        self._gesture_error = False
        self._ownership_uncertain = False

    @property
    def ownership_uncertain(self):
        """Permanent evidence that native work or device closure was not confirmed."""
        return self._ownership_uncertain or self.media.ownership_uncertain

    def _notify(self, callback, *args):
        try:
            callback(*args)
        except Exception:
            log.error('hardware_callback_failed')
            if callback is not self._on_failure:
                self.report_failure(None, 'hardware_callback_failed')

    def report_failure(self, identity, reason):
        self._notify(self._on_failure, identity, reason)

    def dance_finished(self, identity):
        if not self._closed:
            self._notify(self._on_dance, identity)

    async def _native(self, operation):
        worker = Worker(operation, 'hardware-lifecycle')
        self._native_workers.append(worker)
        try:
            return await worker.wait(self._timeout)
        except Exception:
            if worker.thread.is_alive() or isinstance(worker.error, HardwareReleaseError):
                self._ownership_uncertain = True
            raise

    def _paths(self):
        for attr, package, filename in (
            ('alert_path', 'sounds', 'alert_16k.wav'),
            ('search_path', 'sounds', 'search_16k.wav'),
            ('dance_path', 'songs', 'dance_song.wav'),
            ('beats_path', 'songs', 'dance_song_beats.json'),
            ('lights_path', 'songs', 'dance_song_lights.json'),
        ):
            path = (Path(self._media_dir) / package / filename if self._media_dir is not None else
                    self._resources.enter_context(as_file(files(package).joinpath(filename))))
            setattr(self, attr, path)
            if not path.is_file():
                log.warning('Local media resource unavailable: %s', filename)

    async def prepare(self):
        if self._closed:
            raise RuntimeError('Hardware closed')
        if self._prepare_task is None:
            self._prepare_task = asyncio.create_task(self._prepare())
            self._prepare_task.add_done_callback(lambda task: task.exception() if not task.cancelled() else None)
        await asyncio.shield(self._prepare_task)

    async def _prepare(self):
        try:
            await self._native(self._initialize)
            if not self._closed:
                self._prepared = True
        except Exception:
            self.report_failure(None, 'hardware_prepare_failed')
            # Clean up partial constructors only once initialization has exited.
            if all(not worker.thread.is_alive() for worker in self._native_workers):
                await self._native(self._cleanup)
            raise RuntimeError('hardware_prepare_failed') from None
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

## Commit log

2026-09-29 Publish the community project with private working state excluded
    Include the application, current CAD and print inputs, reproducible build guide,
    and contributor tools. Keep local work records and printer activity out of Git,
    with publication checks protecting the public file selection.
    [5975-NeoPixel-Breakout.step, A04.stl, A05.stl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]
2026-09-29 Archive obsolete hardware experiments and clarify component references
    Keep prototype servo probes, old lens templates and unused render records
    in ignored local archives. Retain current dimensions, source attribution and
    fitting guidance in the public hardware references.
2026-09-29 Add writing standard, safety message format and name list to the guide design rules
    Define the audience, sentence and action limits, step order, result and
    recovery lines, and caption rules. Add graded WARNING, CAUTION and NOTICE
    safety messages, one name for each connector, assembly, repeated action and
    printed part, a banned-term list, and two worked example steps. Guide data
    is unchanged; these rules await owner approval before chapters are rewritten.
2026-09-29 Add writing-standard warnings and a fact inventory to the guide checks
    consistency.py check now reports warnings for every limit in the approved
    writing standard (sentence and action length, panels per step, joined
    instructions, plain name before an ID on first use, banned terms, captions
    that repeat their action). Limits and banned terms live in one WRITING table.
    Warnings are printed with per-rule counts and never change ok.
    consistency.py facts prints each step's and part card's technical tokens
    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
2026-09-29 Restructure the build guide into the approved chapters and steps
    Apply the owner-approved chapter and step map: 68 build steps in 16
    chapters plus 9 service steps, with descriptive slug IDs and the map's
    titles. Split steps keep only their own actions, panels, parts and
    hardware allocations, and every step link now points at the step it
    means. Allocation totals and every surviving technical fact are unchanged.
    Remove the progress migration layer: route aliases, the one-time import
    of the earlier preview key and the migration functions. Saved ticks for
    retired IDs are kept but no longer count. The browser check now covers
    stale progress, retired IDs, chapter order and numbering.
    Retire the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
    [service-stand-saddle-J05.stl, service-stand.dxf]
2026-09-29 Show graded safety messages and an open parts, fasteners and tools list on each step
    Add a validated safety entry (warning, caution or notice) for steps and
    panels, rendered before the first panel or the panel's actions, with
    level styling that keeps its label in print. Move two existing hazard
    lines into safety entries. Open the step's you'll-need list by default,
    give tools their own section, and add per-step tool lists taken from
    each step's work, with a check that tool cards list the same steps.
2026-09-29 Rename cryptic connector labels in wiring data and diagrams
    Replace H2, H3 and "pixel" with the approved names (Pi power lead, base
    half, light) in electrical.json, the diagram generators and their tests,
    and regenerate the 26 affected wiring SVGs. Labels only: no connection,
    pin, polarity or fuse value changed, and the fact inventory matches the
    post-U4 baseline.
    electrical.json is a pinned R28 current input, so the owner approved
    re-pinning its fingerprint in current-inputs.json and registry.json.
    No CAD geometry, STL or print file changed, and the design-control check
    logic is untouched; a one-byte tamper still fails the check.
2026-09-29 Add a Before you start page and point the landing page's start button to it
    New readers now reach step 1 in two clicks: the landing page's primary
    button opens Before you start, which names the first action (choose
    filament colors, then start printing plate 2) and has one Start step 1
    button. The page lists the skills assumed, the tools from the parts list,
    a one-screen chapter map, and print time and PLA summed from the plate
    estimates. It shows no assembly time or cost, per the owner's decision.
    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
2026-09-29 Rewrite the Prepare and Print chapters and plate settings to the writing standard
    Split the workbench and printing steps into short panels, move all print
    cleanup into the Clean and check each print step, add a NOTICE for the thin
    plastic behind the front nuts, define test-route and test-fit at first use,
    and rewrite the plate settings prose with the approved names.
    [app.js]
2026-09-29 Rewrite the Base hardware and Base boards and controls steps to the writing standard
    Steps 4-10 and 20-26: one instruction per sentence, plain names with IDs at
    first use, facts moved out of captions into actions, links back moved to
    notes, a NOTICE for the thin plastic behind the front nuts, continuity mode
    named for every meter check, and checks written for the split steps. The
    33-nut total moves to the cradle and power jack nut step's check. No
    quantity, pin, polarity, dimension or allocation changed.
2026-09-29 Glue base nuts only where physics needs it and give each panel one operation
    Delete the separate grille and vent nut step. The front and side grille
    channels are open on the inside, so each grille step now loads its own
    nuts right before the screws and holds each nut with a fingertip until its
    screw catches. Board, cover, cradle, rear vent and power jack nuts stay
    glued, grouped by the base's orientation. Reorder the button step so its
    nuts are loaded right before their screws, fix the power jack mounting
    order to match its pictures, and finish the feet step. Add the
    one-operation-per-panel and physical-sense rules to the writing standard.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
2026-09-29 Rewrite the Base wiring and Light test chapters to the writing standard
    Split each panel into one operation, place the fuse holders before
    cutting their loops, add safety entries at polarity, bypass, fuse-value
    and first power-up hazards, label the S2 outputs and connector halves,
    and add the heat-shrink tool and flush cutters where the work needs them.
    Claude-Session: https://claude.ai/code/session_01EnNd7MYFHgpRwVJFToUq7s
2026-09-30 Rewrite the Frame and servos and Head chapters to the writing standard
    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
2026-09-30 Apply review fixes to the Base wiring and Light test chapters
    Unplug the supply after the polarity reading before the barrel plug
    goes into J1, recheck W1 to W3 once F2 is fitted, name the tied wires
    and the one tie that frees the F2 output end, and split panels so each
    title matches its one operation. Name the Pi pins before the socket
    method, give each pin connection its own sentence, drop explanation-only
    button actions, and match heat-shrink and label consumables to the work.
    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
2026-09-30 Apply review fixes to the Base hardware and Base boards and controls chapters
    Rework the front button fastening so both nuts rest in their pockets with
    the base upside down and the insert is fitted from below with two hands.
    Fit the front and side grilles one screw at a time, add result lines where
    panels allow, put heat-shrink on before both R1 joints, give the USB socket
    check its own panel, use one name for C16, and list C18 where it is offered.
    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
2026-09-30 Apply review fixes to the Frame and servos and Head chapters
    Choose the first eye before routing the mouth leads, give the head
    harness short check an exact meter setting and test points, and move
    the eye-window film warning into a NOTICE before the fitting action.
    Say which hand holds what while the base lies on its side, clear wires
    before the upright screws go in, pin the head-servo bracket with its
    screws before the nuts, name robot sides for the shoulder servos and
    put the dropped-nut recovery right after the first nut hold.
    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
2026-09-30 Apply review fixes to the Prepare, Print and Pi software chapters
    Remove the workbench technique panel and keep test-route in the glossary.
    Put every print option before the print action and correct the print
    order to first need (2 and 7, then 1, 3, 4, 6, 8, 5, 10 and 9). State
    the manifest print total, 39 h 8 min, on both pages and check it at
    build. Split result lines out of Pi software actions.
    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
    [app.js]
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2026-09-30 Cut pointless ceremony from the Prepare to Head chapters
    Remove mid-build checks and reminders with no consequence at that point:
    the repeated bottom-cover clearance checks in steps 9, 30, 31 and 32 (the
    4 mm rule stays once in secure-base-wiring), a result line about speaker
    wires in a step that does not touch them, rechecks already done earlier,
    and reminders about the unprinted cover and untried tests.
    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
2026-09-30 Fix Body chapter review findings
    Mark only the head power pair and give the short-cable recovery its own line;
    split insulating from the meter check; turn P12 before lining it up; tape the
    upper seam backing before the final wrap instead of three-handed under the foam.
    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
2026-09-30 Rewrite the Final wiring chapter to the writing standard
    Lay the robot on its back with the backpack supported, warn against
    swapped servo supply and ground, and tie the new base bundle once. Rest
    the head level with the body to join the head light connector, and move
    the short check after both light connectors. Cut the checks base-check
    already did and the unreachable P13 reference. Clear the chapter's
    writing warnings.
    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
2026-09-30 Rewrite the First power-up chapter to the writing standard
    Raise the robot on towels so the rear power jack hangs clear, fit F1 with
    the fuse-swap guard, run the light test and power checks, then hold the
    fit position and shut down once. Commands and outputs match the software.
    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
2026-09-30 Fix Close up and test review findings and the power jack side
    J1 sits at the robot-left end of the rear face (CAD FB21 transform tx=+16).
    Speaker check now reads the saved level and adjusts only by ear; first
    movement restores the head light cable check and gives a reset path from
    the upright state; approved name input harness replaces body-half wires.
    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
2026-09-30 Place the head light connector inside the head per CAD
    CAD keep-out 'KEEP HEAD SM connector and latch envelope' puts the joined
    head light connector on top of the mouth LED cassette, inside the head,
    above the head shelf. The head light cable, not the head harness, passes
    up through the shelf's front side entry; its loop stays below the shelf.
    Fix head-light-cable, body-light-strand (10 cm mark), light-connections,
    all-lights-test, shelf-arms and head-shoulder-covers to match.
    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
2026-09-30 Rewrite the Service steps to the writing standard
    Replace the service stand with a towel lay-down, add a power-off warning to
    every service step, move head light connector and backpack/belt removal into
    the service steps, and end servo replacement at the fit position.
    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
2026-09-30 Fix Service review findings: servo route, shutdown, poses and safety levels
    Rewrite the servo replacement as a CAD-derived reverse-of-build route, add the
    missing shutdown in body-light-service, keep the power message only on entry
    steps, and fix poses, lead-ins and the shutdown signal across Service.
    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
2026-09-30 Fix second Service review: shutdown wait and servo ear nuts
    Replace the SSH-close shutdown signal with a 30 second wait where the base is
    closed, give arm-service a shaft reset that works with the base closed, add
    recovery for dropped servo ear nuts, point the servo route at the right
    body-light-service panel, and cut a ceremony line.
    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
2026-09-30 Rewrite the reference pages to the writing standard
    Rebuild the Build notes glossary from the name list, turn both
    troubleshooting tables into symptom, check and fix, replace retired
    names on the electrical, software and fastener pages, and cut the
    bench-assembly step tips as ceremony.
    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
    [app.js]
2026-09-30 Rewrite the part and supply cards to the writing standard
    Apply the name list, sentence limits and banned-term rules to all 128
    part cards, match card facts to the current steps (backpack carrier
    nuts, head shelf fastening, glued nut count), fix four card step lists
    and list the heat-shrink tool in the three steps that insulate joints.
    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
2026-09-30 Drop the quick-connects from the catalog and fix the button lead review
    Remove E19 (Adafruit 1152) from supplies.json, the part cards, the
    reference catalogs and the cartoons, and state the 30 cm length in the
    E24 name and exact text so buyers see it on the parts list. The owner
    approved re-pinning supplies.json in current-inputs.json and
    registry.json; only those two fingerprints changed.
    Button lead review fixes: R1 is soldered in line with the LED + tab,
    pointing straight back, under about 25 mm of 1/8-inch heat-shrink; the
    solder pictures are drawn from above as the builder sees them; a new
    drawing shows the leads threaded through FB20 and the nut; the switch
    check gains a recovery line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
2026-09-30 Make the writing rules errors and close the U18 hand-offs
    Writing-standard findings are now errors in consistency.py, so a long
    sentence or a retired name fails the guide build and make check. The
    one-instruction check skips quoted software messages and code, and the
    retired service stand is a banned term. INSTRUCTION-DESIGN.md gains the
    no-pointless-ceremony rule, the towel rule, CAD as fastening source,
    the 1-3 actions per panel limit and a picture rule learned from the
    button drawings.
    Hand-offs: the servo fit reference download matches the current guide;
    the button insert drawing shows the finished fit with numbered order;
    meter probes move to their own check picture; the E18 cartoon ti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
2026-09-30 Plug the shifter leads in before cutting them and fix the U18 review notes
    Each GPIO lead now goes onto its Pi pin first and is cut where it reaches
    its terminal. Names: USB-A extension cable, microSD card (with the two
    generated SVGs regenerated). Ban the old harness-opening names, stop
    straight quotes exempting joined instructions, describe only the picture in
    the secure-wiring caption, keep the audio module connected for provisioning,
    and make the C05 extension length followable.
    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
    [app.js]
2026-09-30 Correct guide assembly visuals and follow-up references
    [app.js]
2026-09-30 Promote approved head, USB cradle and jetpack CAD batch
    [FB24.stl, FB32.stl, P08.stl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]
2026-09-30 Synchronize guide and print files with approved R29 design
    [BlooglyBlob-R28-Optional-Clear-PETG-Ball.3mf, BlooglyBlob-R29-Optional-Clear-PETG-Ball.3mf, BlooglyBlob-R29-PLA-Production.3mf]
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2026-09-30 Make print projects reuse their selected STL meshes
    Resolve all 41 pending instance comparisons with reviewed source frames.
    Regenerate only the A04 antenna STL from unchanged Fusion CAD, preserve print
    settings and modifiers, and refresh reviewed plate previews and estimates.
    Add a candidate-only mesh replacement helper with strict input checks and
    regression coverage for preservation and failed-output cleanup.
    [A04.stl, BlooglyBlob-R29-Optional-Clear-PETG-Ball.3mf, BlooglyBlob-R29-PLA-Production.3mf]
2026-09-30 Apply PR #2 guide review fixes
    Backpack: apply the tank epoxy around each tank after sliding it in to
    the second ring, so the first ring no longer wipes it; split the test-fit
    result from the take-off action and name the bonded parts in the check.
    Route the plugged USB-A extension cable instead of test-routing it.
    Recaption the audio cradle and USB route pictures to what they show.
    Drop the probe-tip reminder from the supply polarity check. Point the
    servo and body-light service steps at the last two backpack panels and
    split their long close-up actions. The P08 card now says to clear stray
    threads from the underside pockets without breaking their roofs.
    CURRENT-NOTES.md now says all 72 pri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
2026-10-01 Keep head openings clear when reslicing print exports
    [BlooglyBlob-R29-PLA-Production.3mf, P08.stl, P14.stl]
2026-10-01 Restore the 5 A supply and correct supply quotes
    Return to the Mean Well GST40A05-P1J supply and YP12_YC12 mains cord.
    The 721AU power jack is rated 5 A and the unfused wiring before the
    fuses relies on the supply's overload shutdown, so the 5.63 A NGE45
    does not fit. Guide steps, safety text, drawings, references and the
    electrical record match main again.
    Correct the quotes the review found: black cable ties at $2.58, the
    25-99 BelMetric tier for M3 nuts and M3x12, stainless SF3X10SS for
    M3x10CS, and Gorilla double-sided tape from Lowe's for C16 in place of
    the unsupported 3M 4905 price. Remove prices from card text, point
    cards at the priced products, add buying choices to the shopping l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
    [app.js]
2026-10-01 Make cost totals add up and tighten shopping list wording
    Round each cost row to cents and sum the rounded rows, so every subtotal
    and total on the guide adds up. Validate alternative purchase links as
    HTTPS, name the part in data errors, and cover included accessories,
    bad URLs and missing allowances in tests. Use one name per figure
    (Materials used, Shopping total), show bare counts for single items,
    move shopping notes into the price catalog and keep the live total
    outside the rebuilt shopping list.
    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
    [app.js]
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2026-10-03 Credit Adafruit's MIT board models in the CAD
    The assembly (.f3d and the new STEP) embeds unmodified 5975 and 6066
    models from Adafruit CAD Parts, which is MIT licensed, but the repo
    carried no copy of that notice. The build guide also credited these
    models as CC BY-SA, which applies only to Adafruit's Eagle board files.
    Add Adafruit's MIT notice, name the files that contain the models in
    LICENSING.md, list the local 5975 STEP with its source, and correct the
    guide credit.
    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
    [app.js]
2026-10-03 Warn about magnets, cloud audio and API costs in the safety notice
    The hands attach with small neodymium magnets, and the notice allows
    supervised use by children, but it only covered magnets as "small
    parts". Swallowed magnets cause serious internal injury, so name the
    hazard in the notice and on the step where builders handle loose
    magnets.
    Also tell builders that speech goes to OpenAI under their account, that
    they must follow OpenAI's terms (including its rules on children), and
    that they're responsible for API charges. Add a non-affiliation line for
    the companies named in the project.
    Claude-Session: https://claude.ai/code/sessio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
    [app.js]
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2026-10-03 Use a Fusion presentation capture for the main robot image
    Replace the renderer-drawn front view with a shaded capture from Fusion's
    Design workspace, which shows the real appearances (copper trim, ivory
    body) on a transparent background. Record its source hash, camera,
    lighting and export settings in presentation-front.json, document how to
    recapture it, and drop the scene from render_models.py so the illustration
    generator leaves it alone. Regenerate the link-preview card from it.
    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
2026-10-04 Ignore a commented RING_TOKEN when checking for a saved Ring login
    The setup helper treated any "RING_TOKEN=" text as a saved token, so
    the commented example line in app.env triggered the overwrite prompt.
    has_saved_token() now reads the file with deploy_config.read_env, which
    skips comments and empty values.
    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
    [test_integration_configuration.py]
2026-10-04 Tighten license scope, third-party notices and attribution
    Review the project's licensing and attribution and fix what was missing
    or inaccurate:
    - LICENSING.md names DeMartini Studios LLC as the rights holder, lists
    every CAD component that contains the Adafruit 5975 and 6066 models
    (including the visible Shifter parts), names the Eagle file's exact
    CC BY-SA 3.0 Unported license, excludes the Imager screenshots,
    typefaces, GitHub mark, Contributor Covenant text and the DeMartini
    Studios logo from MIT, and adds a Names and logos section.
    - The guide footer's Credits & licenses panel, which only listed the
    typefaces, now also credits the project's MIT license, the Adafruit
    boar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
    [analyze_song_lights.py, app.js]
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2026-10-04 Animate the homepage robot lights (#11)
    * Animate the homepage robot lights
    * fix(ci): wait for the hero to leave the viewport
    * Keep homepage animation sharp and accessible
    * Keep homepage animation script with authored guide code
    [app.js]
2026-10-05 Remove servo branch fuse and retain lighting protection (#12)
    [assembly.f3d]
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2026-10-09 Bring the build guide, R33 CAD and Pi software in line with the owner bench build (#14)
    [BlooglyBlob-R29-PLA-Production.3mf, BlooglyBlob-R33-PLA-Production.3mf, P04.stl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]
2026-10-09 Use towels in the build guide only where they prop or cushion (#15)
    The base on its side, the face-down head and the standing robot now rest
    on the bench. Lying on its back, the robot is propped level on a couple
    of folded towels, with weight kept off the head once it is fitted. The
    loose head rests on towels during the light test so its cable does not
    pull, instead of on a stack built up to the height of the body.
    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
2026-10-09 Keep conversation audio responsive and give tool announcements one owner
    Parse Responses payloads in owned workers so SDK schema construction cannot
    block audio processing. Keep microphone capture running while retiring
    speculative playback during delegated decisions.
    Use explicit delegation guidance and let the application own sleep and dance
    announcements. Resume speech when nonterminal work starts, preserve scanner
    conversation, and fence terminal actions against newer user input.
    Add regressions for parsing, cancellation, capture continuity, playback
    handoff ordering, and compound-action corrections. Validated with make check
    and bounded synthetic conversations through the installed Pi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
    [diagnostics.py, evaluate_openai_models.py]
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2026-10-13 Expose microphone callback gaps and stalls between diagnostic reports
    Measure event-loop delay every 100 ms while retaining ten-second summaries.
    Report capture callback spacing separately from capture-worker queue age.
    This corrects an observability blind spot; the isolated PortAudio overflow
    has not reproduced and is not claimed fixed.
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2026-10-14 Make talking gestures restrained and coordinated
    Replace independent arm cycles with one small gesture and shared rest.
    Preserve speech timing, cancellation and explicit motion ownership, including
    a missed-frame return that cannot replay its peak when speech resumes.
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2026-10-16 Simplify project documentation and retire pending guide reviews
    Separate builder guidance from agent maintenance notes, preserve technical
    constraints and evidence, and clarify prototype experience and testing limits.
    Correct stale wiring and nut-retention guidance without changing geometry or
    print settings.
    Remove the manual guide-review checklist and its consumers while retaining
    automated content, input-integrity and browser checks. Keep safety and license
    notices in the guide and download packages, and refresh the two README bindings.
    Validated with make check, staged publication checks, documentation links and
    preservation checks for safety notices, software contracts and hardware in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
